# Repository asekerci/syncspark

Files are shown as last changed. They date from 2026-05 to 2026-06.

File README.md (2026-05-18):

# SynchroSpark Swarm: Mobile Robots for Exploring Swarming, Synchronization, and Formation Control Algorithms

<p align="center">
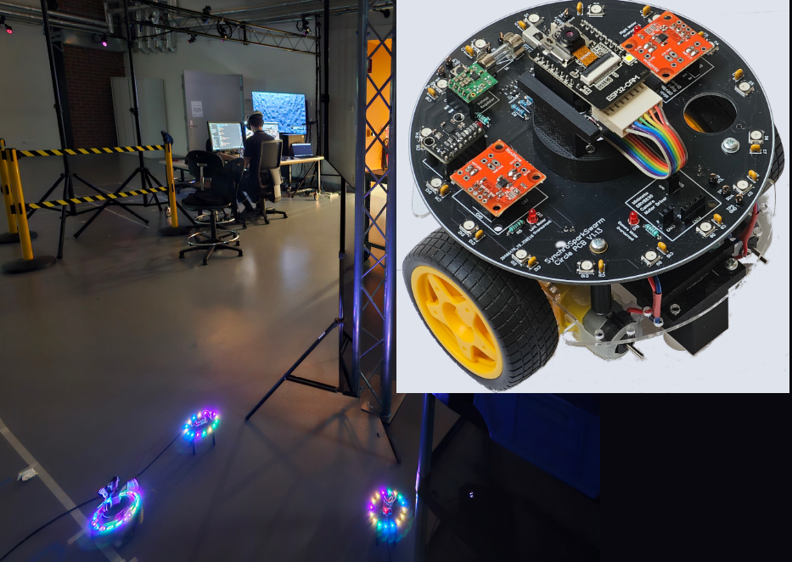
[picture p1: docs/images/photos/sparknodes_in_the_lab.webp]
Three SparkNode prototypes used in the SyncSpark project
  
</p>

## Table of Contents

- [Introduction](#introduction)
- [Project Objectives](#project-objectives)
  - [Formation Control Algorithms](#formation-control-algorithms)
  - [Research Collaboration](#research-collaboration)
- [Licensing](#licensing)
- [Project Structure and Terminology](#project-structure-and-terminology)
  - [About the Repository](#about-the-repository)
  - [AI Thinker ESP32-CAM Module](#ai-thinker-esp32-cam-module)
  - [Software Development Platform](#software-development-platform)
- [Testbed Configuration and Operation](#testbed-configuration-and-operation)
  - [Remote Control of SparkNodes with MQTT](#remote-control-of-sparknodes-with-mqtt)
  - [Over-the-Air (OTA) Method for Firmware Upgrades](#over-the-air-ota-method-for-firmware-upgrades)
- [Programs for Testing and Demonstrating Various Functionalities](#programs-for-testing-and-demonstrating-various-functionalities)
  - [OTA Enabled Programs](#ota-enabled-programs)
  - [Directly Flashable Programs](#directly-flashable-programs)
- [Appendix A: Additional Steps to Create an ESP-IDF Project From Scratch](#appendix-a-additional-steps-to-create-an-esp-idf-project-from-scratch)
- [Appendix B: ESP32-CAM Configuration](#appendix-b-esp32-cam-configuration)
- [Appendix C: Custom Partition Table](#appendix-c-custom-partition-table)

## Introduction

We[^1] are developing a network of low-cost mobile robots for exploring swarming, synchronization, and formation control algorithms, hence the name
**SynchroSpark Swarm**. The project's short name is **SyncSpark**, which is
also the name of our main GitHub repository.

Each robot, called a **SparkNode**, features a wheeled base with two motors and
an ESP32-CAM AI-Thinker module. At present, the module is mounted in a fixed
position, but we plan to place it on a motorized rotating platform in a future
revision. That change will let us control the camera angle for 360-degree
observation and better support the study of fully localized algorithms.

## Project Objectives

When we started designing the SparkNodes, our goal was to experiment with
cooperative robotics and explore the intersection of art and technology, with a
particular focus on collaborative robot art. To support that goal, we wanted a
mobile robot platform that was low-cost, compact, practical to build in
quantities of 30 to 40 units, well connected, and easy to track, at least at the
level of relative pose.

These constraints shaped the project from the beginning. Because cost is a
central concern, our robots do not rely on sophisticated sensors. Instead, we
build on several low-cost localization strategies drawn from our past research,
including:

- The use of RGB LED rings and cameras, as described in [Partitioning de Bruijn
  Graphs Into k-cycles for Robot Identification and
  Tracking](https://sekerci.info/~ahmet/papers/de_bruijn_cycles.pdf) (T.
  Grubman, Y. A. Sekercioglu, and D. Wood), and
- Trilateration methods, as explored in
  [Accurate Node Localisation in Ad Hoc Networks Using Directional Pulsed
  Infrared Light
  Communications](https://sekerci.info/~ahmet/pgrad-projects/joseph-thesis.pdf)
  (J. Violi, MEngSc. Thesis).

The concepts developed in these studies provide the technical basis for implementing formation control algorithms on the swarm and, ultimately, creating coordinated dynamic art displays.

<p align="center">
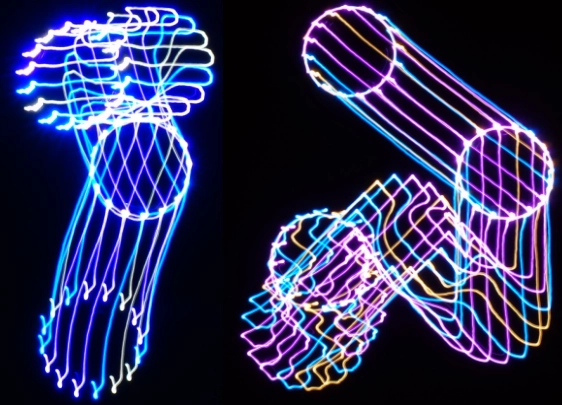
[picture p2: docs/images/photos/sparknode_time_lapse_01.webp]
Long-exposure image of two SparkNodes creating light trails during motion
  
</p>

<p align="center"><em>Long-exposure image of two SparkNodes moving randomly, illustrating the project's potential for collaborative robot art.</em></p>

### Formation Control Algorithms

Based on our past research in [formation control techniques](https://sekerci.info/~ahmet/networked_robotics/history.html), we believe that well-established decentralized algorithms are the right starting point for this platform. They allow us to study how simple local interaction rules can produce emergent collective behaviour. The [Boids algorithm](https://en.wikipedia.org/wiki/Boids) is a natural first example and will serve as our initial demonstration project.

Our second line of work is "Distributed Formation Control Using Computational Energy Minimization." This approach is inspired by our earlier work, [Virtual Localization for Mesh Network Routing](https://sekerci.info/~ahmet/mesh/virt_loc/) (N. Moore, Y. A. Sekercioglu, and G. K. Egan). In this approach, each robot moves toward a position that minimizes a local computational energy function, allowing formations to emerge without central coordination.

In our virtual localization study, static nodes iteratively estimated their positions by minimizing a local potential based on the virtual positions of their one-hop and two-hop neighbours, which were also computed iteratively. Although that idea was originally applied to sensor-network localization in support of geographic routing, the same principle can be adapted to mobile robots by translating virtual positions into real motion.

### Research Collaboration

The project has also grown into a research collaboration with the [Shortest Path Lab (SPL)](https://pathfinding.ai) at Monash University, led by A/Prof Daniel Harabor. This collaboration focuses on building a mobile robot network for testing multi-agent pathfinding algorithms in realistic physical scenarios.

SPL works on AI planning and heuristic search algorithms for single-agent and multi-agent pathfinding problems, including trip planning in transportation networks, motion planning and navigation for mobile robots, and automated warehouse logistics. SyncSpark provides a practical testbed for moving some of those ideas out of simulation and into embodied multi-robot experiments.

As part of this collaboration, we also extended the project into the mixed-reality world by creating [SparkVerse](./docs/system/sparkverse.md), a virtual environment for testing algorithms before physical implementation. Together, the physical SparkNode platform and SparkVerse allow us to study these ideas across both simulated and real-world settings.

## Licensing

This repository contains both software and hardware design materials, so its licensing is organized by content type.

- Software source code is licensed under the GNU General Public License v3. See [LICENSES/GPL-3.0.txt](./LICENSES/GPL-3.0.txt).
- Hardware design files under [docs/hardware](./docs/hardware) are licensed under the CERN Open Hardware Licence Version 2 - Strongly Reciprocal. See [docs/hardware/README.md](./docs/hardware/README.md) and [LICENSES/CERN-OHL-S-2.0.txt](./LICENSES/CERN-OHL-S-2.0.txt).

If a file or subdirectory carries a different license notice, that notice takes precedence for that material.

## Project Structure and Terminology

### About the Repository

This repository is organized as an umbrella project (or monorepo) that contains multiple ESP-IDF application projects and shared components:

- **Umbrella Project (Monorepo):** The top-level directory (`syncspark`) that
  contains several ESP-IDF application projects and common components.
- **Application Project (Subproject):** Each subdirectory under the umbrella
  (e.g., `sparknode_cam_wifi`, `sparknode_ota_updater`) that represents a standalone
  ESP-IDF project with its own `main` folder, `sdkconfig`, etc.
- **Component:** Shared code or libraries (e.g., in `components/`) that can be
  reused by multiple application projects.

Throughout this documentation, these terms are used to distinguish between the
overall repository, the individual ESP-IDF projects, and the reusable code
modules.

At a practical level, the top-level repository is centered around a small set of
directories:

- [components](./components/): shared ESP-IDF components reused across projects.
- [docs](./docs/): hardware, architecture, and supporting project documentation.
- [system](./system/): host-side utilities such as OTA packaging and log collection.
- [sparkcore](./sparkcore/): the primary OTA-enabled firmware for SparkNodes.
- [sparknode_ota_updater](./sparknode_ota_updater/README.md): the factory-partition OTA updater.
- [get_esp32_chip_info](./get_esp32_chip_info/README.md): the simplest direct-flash sanity check for a board/toolchain.

### AI Thinker ESP32-CAM Module

We use the AI Thinker ESP32-CAM module, which is built around the original dual-core
ESP32 chip (not the newer ESP32-S2, ESP32-S3, or ESP32-C3 variants). The module
provides WiFi and Bluetooth capabilities and has the following specifications:
a 240 MHz clock speed, 520 KB of RAM, 8 MB of PSRAM (SPIRAM)[^2], and 4 MB of flash memory.

### Software Development Platform

We use the [Espressif IoT Development
Framework (ESP-IDF)](https://github.com/espressif/esp-idf). [Visual Studio Code](https://code.visualstudio.com/), paired with the [ESP-IDF
extension](https://docs.espressif.com/projects/vscode-esp-idf-extension/en/latest/),
provides an effective development environment.

To test the toolchain, we use a small program called
[`get_esp32_chip_info`](get_esp32_chip_info/README.md), which reports information
about the chip and its capabilities. This program should be flashed directly to the
factory partition via a USB cable.

## Testbed Configuration and Operation

<p align="center">
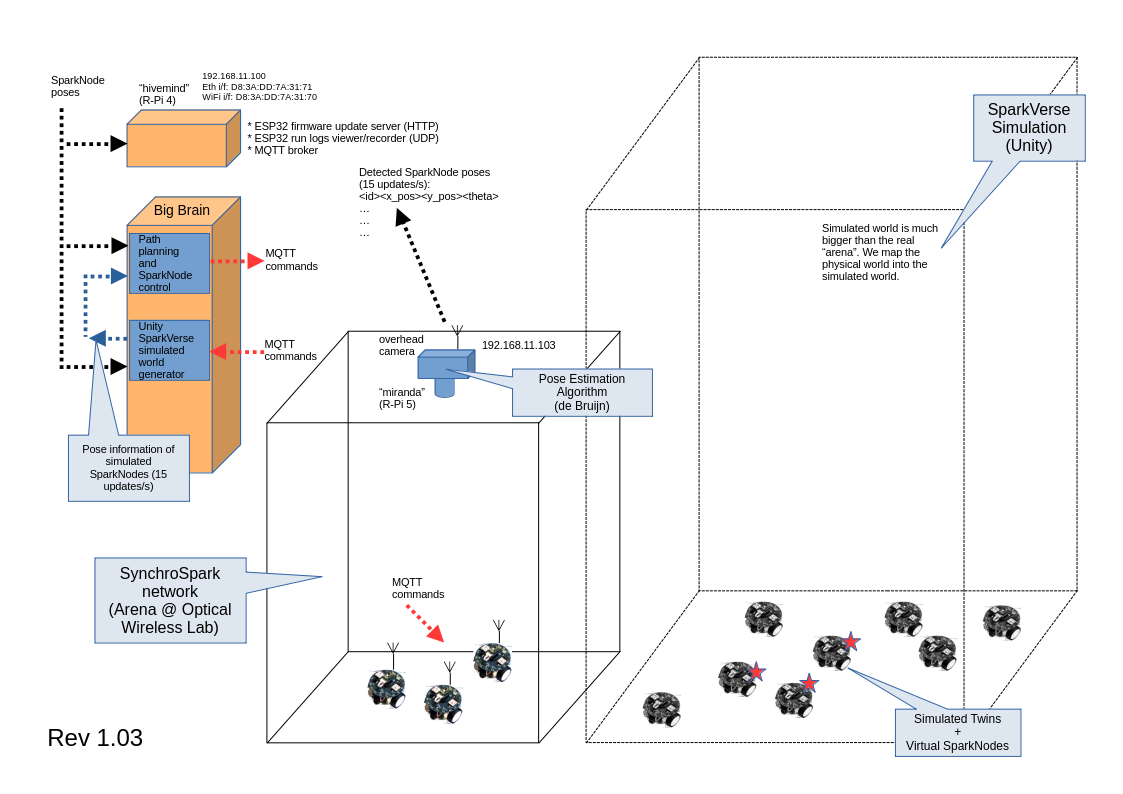
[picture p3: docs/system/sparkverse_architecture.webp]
Robotics Lab testbed
  
</p>

<p align="center"><em>The robot-network setup at the Monash Optical Wireless Systems Laboratory. The diagram also shows the Unity-based simulation environment. The Unity simulation environment has its own separate GitHub repository, which is currently under preparation.</em></p>

### Remote Control of SparkNodes with MQTT

We are progressively adding MQTT commands for the remote control of SparkNodes. See
[the information and list of commands](./docs/software/mqtt.md) for details.

### Over-the-Air (OTA) Method for Firmware Upgrades

We primarily use the over-the-air (OTA) method for firmware upgrades, as
described below. Our OTA firmware update method offers two main advantages:

1. It eliminates the need for USB cable connections, allowing us to quickly
   deploy firmware updates and bring a SparkNode online for testing.
2. Since we plan to have at least 30 SparkNodes in our SynchroSpark Swarm, the OTA method enables us to efficiently update firmware on all of them.

However, the OTA method requires a WiFi LAN, and directly flashing programs is
sometimes more useful for testing basic functionality. For that reason, we group our ESP-IDF projects into two categories:

- [OTA enabled programs](#ota-enabled-programs), and
- [Directly flashable programs](#directly-flashable-programs)

We provide the example application `sparknode_sample_ota_app`, which
demonstrates the basic operation of OTA-enabled firmware. When
`sparknode_ota_updater` is installed in the factory partition of the ESP32-CAM, all other applications should be built from `sparknode_sample_ota_app` as a starting point. These applications are designed to be delivered via OTA updates and should not be flashed directly to the chip over USB.

See [sparknode_ota_updater/README.md](sparknode_ota_updater/README.md) for
detailed information about our OTA firmware update scheme.

[Follow these steps](./docs/software/ota.md) to create OTA-capable firmware. If you need to create a new ESP-IDF project from scratch, see [Appendix A: Additional Steps to Create an ESP-IDF Project From
Scratch](#appendix-a-additional-steps-to-create-an-esp-idf-project-from-scratch).

## Programs for Testing and Demonstrating Various Functionalities

### OTA Enabled Programs

- **[`sparkcore`](sparkcore/)**: The main firmware we run on
  the SparkNodes.
- **[`sparknode_sample_ota_app`](sparknode_sample_ota_app/README.md)**: Used for
  testing and demonstrating the OTA firmware update method. It can serve as
  a starting point for new SyncSpark firmware.
- **[`sparknode_ledring`](sparknode_ledring/README.md)**: For testing the RGB LED
  ring control routines.
- **[`sparknode_mqtt`](sparknode_mqtt/README.md)**: For experimenting
  with MQTT. The `scripts` directory contains examples of
  SparkNode remote control.
- **[`sparknode_drive_test`](sparknode_drive_test/README.md)**: For testing the
  motor drivers.
- **[`sparknode_cam_wifi`](sparknode_cam_wifi/README.md)**: Demonstrates basic
  networking by periodically sending captured image frames to a remote host
  via UDP datagrams over WiFi.
- **[`sparknode_icm20948`](sparknode_icm20948/README.md)**: Performs sensor
  calibration and data acquisition using the ICM20948 9-axis IMU and BMP388
  barometric pressure sensors, and applies the Madgwick sensor fusion
  algorithm for accurate orientation estimation.
- **[`sparknode_i2c_test`](sparknode_i2c_test/README.md)**: For testing I2C
  communication with the motor controllers, BMP388 sensor, and GY-912 IMU board,
  and for verifying RGB LED ring operation.
- **[`sparknode_hall_sensors`](sparknode_hall_sensors/README.md)**: Tests the
  hall-effect sensor routines using interrupts.

### Directly Flashable Programs

- **[`get_esp32_chip_info`](get_esp32_chip_info/README.md)**: Reports on the
  configuration of the chip and performs quick checks.
- **[`sparknode_ota_updater`](sparknode_ota_updater/README.md)**: Flashed
  directly into the factory partition once to enable OTA firmware updates. It must
  remain resident in the factory partition for proper operation of OTA firmware
  updates.
- **[`glow_ledring`](glow_ledring/README.md)**: Illuminates the RGB LED ring
  with the assigned de Bruijn sequence (we allocate unique IDs to each
  SparkNode by using their base MAC addresses).
- **[`opti_pose`](opti_pose/README.md)**: Periodically captures images. We plan
  to use it to develop pose estimation algorithms that will run directly on the
  ESP32-CAM.

## Appendix A: Additional Steps to Create an ESP-IDF Project From Scratch

1. **Navigate to the main SyncSpark project directory:**

   ```bash
   cd $HOME/projects/syncspark/
   ```

2. **Create a new project:**

   ```bash
   idf.py create-project my_esp_project
   ```

   Replace `my_esp_project` with your desired project name. This command
   creates a directory named `my_esp_project` under the current directory and
   populates it with starter files and subdirectories.

3. **Set target:**

   ```bash
   cd my_esp_project && idf.py set-target esp32
   ```

   The ESP32-CAM uses the original ESP32 chip (ESP32-WROOM-32).

After creating your new project, follow the remaining steps in the
[OTA workflow documentation](./docs/software/ota.md).

## Appendix B: ESP32-CAM Configuration

Before generating a binary to run on a SparkNode, several ESP32 chip
properties must be configured, and a custom partition table must be
established. To accomplish this, we created an `sdkconfig.defaults` file.
Using this file, the toolchain configures the following properties correctly:

- **Serial flasher config**: Increases the flash size to 4 MB.
- **Serial flasher config → Flash SPI speed**: Increases to 80 MHz.
- **Component config → ESP System Settings**: Increases the clock speed to 240
  MHz.
- **Component config → ESP PSRAM**: Enables support for PSRAM.
- **Component config → ESP PSRAM → Support for external, SPI connected RAM →
  SPI_RAM config → set RAM speed**: Sets to 80 MHz.
- **Partition Table → custom partition table CSV**: Selects this option and
  sets 0x8000 as the "Offset of partition table".

The standard `sdkconfig.defaults` file is located in the top-level directory of
the SynchroSpark project. The top directory of each individual ESP-IDF project
contains a symbolic link that points to it.

See [sdkconfig and configuration
management](docs/software/about_sdkconfig.md) for further details.

## Appendix C: Custom Partition Table

All OTA-enabled programs use the standard partition table shown below. The main
directory of each OTA-enabled program contains a symbolic link to this standard
partition table.

```bash
    # SynchroSpark Project partition table
    # --> ESP-IDF requires partitions to be aligned to a 4 KB boundary
    # (multiples of 0x1000). In addition to this:
    # --> Partitions of type "app" have to be placed at offsets
    # aligned to 64 KB boundary (multiples of 0x10000).
    #
    # Name,   Type, SubType, Offset,  Size, Flags
    nvs,      data, nvs,     0x9000,  0x6000,
    phy_init, data, phy,     0xf000,  0x1000,
    factory,  app,  factory, 0x10000, 0xF8000,
    ota_data, data, ota,     0x108000,0x2000,
    ota_0,    app,  ota_0,   0x110000,0x2F0000
```

Note that the directly flashable programs use the built-in default partition
table.

## Footnotes

[^1]: Ahmet Sekercioglu and Ismet Atalar, creators of the SyncSpark project.

[^2]: Unfortunately, the current version of ESP-IDF allows us to use only half of the available PSRAM capacity.

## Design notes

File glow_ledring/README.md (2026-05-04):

# RGB LED Ring Illumination
## Overview

This program illuminates the RGB LED ring of a sparknode with the 
assigned deBruijn sequence. 

## ESP32-CAM and ESP-IDF Configuration

Configuration details are in 
the main [README.md](../README.md) file of the **SyncSpark** project.

## Required Components

Run the following commands  in the top directory of the project:

1. **espressif/led_strip**, to add:
 `idf.py add-dependency "espressif/led_strip^3.0.0"`

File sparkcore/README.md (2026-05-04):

# Main Firmware of SparkNodes 

## Overview

This is the firmware we run on the SparkNodes. We install 
it through the OTA method. 

## ESP32-CAM and ESP-IDF Configuration

Configuration details (including the partition table) are in 
the main [README.md](../README.md) file of the **SyncSpark** project.

## Required Components

1. espressif/led_strip:  
 `idf.py add-dependency "espressif/led_strip^3.0.0"`

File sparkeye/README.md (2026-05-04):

sparkeye runs on a camera attached Raspberry Pi 5 to track SparkNodes. 
It has its own separate github repository.

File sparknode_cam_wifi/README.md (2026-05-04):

# _sparknode_cam_wifi_

## ESP32-CAM
Clock speed: 240 MHz, 520 KB RAM, 8 MB PSRAM (SPIRAM), 4 MB flash memory

## About the Program

This program takes a picture every 20 seconds and sends it to a
destination over UDP.

My starting point was the example program provided in the Espressif
esp32-camera component. I removed the parts that are not related
esp32-cam. 

## ESP32-CAM and ESP-IDF Configuration

Configuration details  are in 
the main [README.md](../README.md) file of the **SyncSpark** project.

### Required Components

1. Run this command in the top directory of the project to add the `espressif/esp32-camera component`: 
   `idf.py add-dependency "espressif/esp32-camera^2.0.15"`
2. If you want to have more control over the camera and
   how it will be initialized, you can have your own `Kconfig` file. Copy the content from
   `https://github.com/espressif/esp32-camera/blob/master/Kconfig` into a local `Kconfig`.
   This file should reside in the `main` directory. Currently we use the default one residing in the esp32-camera component.

## Usage and Specific Configurations

### Wi-Fi Connection

Copy the file `wifi_credentials.h.template` to `wifi_credentials.h` (in the `main` directory) and then edit it to set the WiFi SSID and password to connect to your own Wi-Fi network (`wifi_credentials.h` will **not** be uploaded to the github repository). 

### Network Configuration 

We send two separate UDP datagrams to a remote host: One for images, 
and one for the copies of the log messages. 
See `network_config.h.template` for further details. Copy `network_config.h.template` to a file `network_config.h` and edit the remote host's details. 

### Receiving Images

In my case, the destination is my homelab Linux server `rama.local` (`192.168.1.201`), and 
the destination UDP port is `10000`.

On `rama`, I run the python program `rcv_frames_udp.py` to save 
the received image frames. The program is in the top project directory. It saves the received frames in the `frames` directory. In order to run it on `rama`, I first link my RPi5 home directory to `rama`'s `~/systems/sinope` directory by using the command 
`sshfs sinope.local: ~/systems/sinope`. Then, I run the command `rcv_frames_udp.py` on `rama` to listen to the messages sent by the robot (to-do: we need to create a more sophisticated program for receiving image frames from multiple robots simultaneously).

### Receiving Copies of Log messages

The robot sends the copies of log messages to UDP port 10001 of `rama`. Run the command `nc -u -l 10001` on a terminal to display them.  

## Espressif's Notes

- A recommended way is to follow the instructions on this [docs page](https://docs.espressif.com/projects/esp-idf/en/latest/api-guides/build-system.html#start-a-new-project).

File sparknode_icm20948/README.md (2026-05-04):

# ICM20948 IMU Chip Calibration and Experiments
## Overview

- Supports the ICM20948 9-axis IMU sensor and BMP388 barometric pressure sensor via I2C.
- Performs sensor calibration and data acquisition.
- Implements Madgwick sensor fusion algorithm for orientation estimation.

## ESP32-CAM and ESP-IDF Configuration

Configuration details are in 
the main [README.md](../README.md) file of the **SyncSpark** project.

## Required Components

Run the following command  in the top directory of the project:

1. **espressif/led_strip**:
 `idf.py add-dependency "espressif/led_strip^3.0.0"`

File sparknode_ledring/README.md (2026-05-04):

# SparkNode RGB LED Ring deBruijn Patterns Demo
## Overview

This program lights up the RGB LED ring of a sparknode with the
assigned deBruijn sequence. 

It is MQTT enabled. 

## ESP32-CAM and ESP-IDF Configuration

Configuration details (including the partition table) are in 
the main [README.md](../README.md) file of the **SyncSpark** project.

## Required Components

1. espressif/led_strip:  
 `idf.py add-dependency "espressif/led_strip^3.0.0"`

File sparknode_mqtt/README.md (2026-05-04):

# MQTT Demo

## Overview

This ESP-IDF project is for testing the MQTT scheme, which enables remote 
control of SparkNodes via MQTT commands. 

The remote control commands include driving forward/reverse, turn left/right, stop
immediately, and reboot on command. We keep adding the new ones.    

The details are [here](../docs/software/mqtt.md).

## ESP32-CAM and ESP-IDF Configuration

Configuration details (including the partition tabl) are in the main
[README.md](../README.md) file of the **SyncSpark** project.

## Required Components

1.  espressif/led_strip:\
    `idf.py add-dependency "espressif/led_strip^3.0.0"`

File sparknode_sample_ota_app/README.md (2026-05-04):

# SparkNode Sample Over-The-Air (OTA) Application
## Overview

When the chip is programmed for the very first time, 
we flash `sparknode_ota_updater` in the `factory` partition by using a
USB cable.

 Then, whenever the chip is rebooted, or power-cycled, it 
 downloads a binary file and its corresponding MD5 checksum from the server specified in `network_config.h`. If the download is successful, the binary is written to the `ota_0` partition, the boot partition is set to `ota_0`, and the chip is restarted.

On subsequent boots, if the downloaded binary is properly configured 
the application changes the boot partition to `factory` to check the 
availability of updated firmware by running `sparknode_ota_updater` 
at every restart. 

This is a sample application that can be used as a starter for all
firmware sources for the SynchroSpark Project. 

## ESP32-CAM and ESP-IDF Configuration

Configuration details (including the partition table) are in 
the main [README.md](../README.md) file of the **SyncSpark** project.

## Software Configuration Before the First Compilation 

Configuration details (including the partition table) are in 
the main [README.md](../README.md) file of the **SyncSpark** project.

## Required ESP-IDF Components

- led_strip, run this command:
```bash
   idf.py add-dependency "espressif/led_strip^3.0.0"
```

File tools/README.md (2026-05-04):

# Python Tools Summary

## mqtt_orientation_viewer.py
Live 3D viewer for yaw/pitch/roll over MQTT. Renders a simple 3‑wheel robot model.

Usage:
```bash
python mqtt_orientation_viewer.py --broker 192.168.1.19 --node sparknode03
```

Options:
- `--topic <topic>`: override topic (default: `arena/<node>/orientation`)
- `--poll-ms <int>`: UI update interval (ms)
- `--yaw-offset <deg>`: alignment offset (default -90)
- `--invert-yaw`, `--invert-pitch`, `--invert-roll`

Notes:
- Requires `numpy`, `matplotlib`, `paho-mqtt`.
- Needs an interactive backend (PyQt5 or Tk). If none found, it fails with a message.

## mag_calibrate_3d_all_in_one.py
All‑in‑one 3D magnetometer calibration pipeline: capture samples → fit ellipsoid → apply calibration.

Usage:
```bash
python mag_calibrate_3d_all_in_one.py --broker 192.168.1.19 --node sparknode03 --samples 500 --delay-ms 50
```

Options:
- `--mode all|capture` (default: `all`)
- `--timeout-s <sec>`
- `--output <csv>`
- `--target-radius <uT>` (optional fixed scaling)

Notes:
- Uses `mosquitto_sub` and `mosquitto_pub`.
- Default output: `mag_capture_<node>.csv`.

## mag_capture_to_csv.py
Captures raw magnetometer samples into a CSV file.

Usage:
```bash
python mag_capture_to_csv.py --broker 192.168.1.19 --node sparknode03 --samples 500 --delay-ms 50 --trigger
```

Options:
- `--trigger`: sends `calibrate mag capture <samples> <delay_ms>` before listening.
- `--output <csv>`
- `--timeout-s <sec>`

## plot_heading_vs_euler.py
Plots heading vs yaw (top) and pitch/roll (bottom) from a log `.txt` or a CSV.
Also writes optional CSV output and annotates filename, start/stop times, and mode.

Usage (TXT input):
```bash
python plot_heading_vs_euler.py log_YYYYMMDD_HHMMSS.txt --csv-out heading_vs_yaw_YYYYMMDD.csv
```

Usage (CSV input):
```bash
python plot_heading_vs_euler.py heading_vs_yaw_YYYYMMDD.csv
```

Options:
- `--no-unwrap`: keep 0–360 wrap instead of unwrapped angles

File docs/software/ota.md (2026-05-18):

#### OTA: One-Time Setup

Before generating any binaries, complete the following steps:

1. **Configure template files:** Locate
   [`wifi_credentials.h.template`](./components/syncspark_config/include/wifi_credentials.h.template)
   and
   [`network_config.h.template`](./components/syncspark_config/include/network_config.h.template)
   in the
   [`components/syncspark_config/include`](./components/syncspark_config/include/)
   directory, then follow these steps:
   1. **WiFi Connection**: Copy the contents of `wifi_credentials.h.template`
      to a new file named `wifi_credentials.h`[^3] and update the WiFi
      connection information as described in the file comments.
   2. **IP Address Configuration**: Copy the contents of
      `network_config.h.template` to a new file named `network_config.h`[^4]
      and update the IP addresses as described in the comments.
2. **Flash the OTA updater:** Flash `sparknode_ota_updater` directly over USB
   cable (**this will be placed in the _factory_ partition by default**), then
   disconnect the USB cable. Here are the **detailed flashing steps**
   (assuming the ESP-IDF toolchain is installed in `$HOME/esp`, version v5.5,
   and the SyncSpark repository is cloned to `$HOME/projects/syncspark`):
   1. Set up the environment: `source $HOME/esp/v5.5/esp-idf/export.sh`
   2. Navigate to the updater directory:
      `cd $HOME/projects/syncspark/sparknode_ota_updater`
   3. Configure the project: `idf.py reconfigure` (this command generates a
      `sdkconfig` from the `sdkconfig.defaults`).
   4. Build the binary: `idf.py build`
   5. Prepare the ESP32-CAM for flashing: Connect the ESP32-CAM to your
      computer via a USB cable. Press and hold the IO0 button, then press the
      ESP32-CAM reset button. Release the reset button first, then release the
      IO0 button. The chip is now ready for flashing.
   6. Flash and monitor: `idf.py flash monitor` (this command flashes the
      firmware to the factory partition).

The board is now ready for OTA updates. Disconnect the USB cable.

#### OTA: Typical Workflow

To generate a binary for an existing [SynchroSpark
program](#programs-for-testing-and-demonstrating-various-functionalities)[^5] in
the repository (for example, to run `sparknode_sample_ota_app` on a SparkNode
after cloning the SynchroSpark project sources to `$HOME/projects/syncspark`),
follow these steps:

1. **Activate the HTTP Server and Log Listener:**
   - Run the HTTP server on the target host (see the command in `network_config.h`)
   - Run [`log_listener.py`](./system/utilities/log_listener.py) on the
     listener host

2. **Set up the environment:**

   ```bash
   source $HOME/esp/v5.5/esp-idf/export.sh
   ```

   (Your ESP-IDF version may differ; please check your installation
   directory.)

3. **Navigate to the program's main directory:**

   ```bash
   cd $HOME/projects/syncspark/sparknode_sample_ota_app
   ```

4. **Add required dependencies:** Some projects require additional ESP-IDF
   standard components. For example, `sparknode_led_ring` needs the RGB LED
   strip component. To add it, run:

   ```bash
   idf.py add-dependency "espressif/led_strip^3.0.0"
   ```

   Please refer to each project's `README.md` for required system
   components.

5. **Configure the project:** Run:

   ```bash
   idf.py reconfigure
   ```

   to configure system parameters and set a custom partition table. For
   details, see [Appendix B: ESP32-CAM
   Configuration](#appendix-b-esp32-cam-configuration) and [Appendix C: Custom
   Partition Table](#appendix-c-custom-partition-table).

6. **Build the project:** Run:

   ```bash
   idf.py build
   ```

   in the top directory of the program (e.g.,
   `$HOME/projects/syncspark/sparknode_sample_ota_app`).

7. **Prepare the OTA binary:** Run:

   ```bash
   ../system/utilities/prep_ota_bin.sh <SparkNodeID>
   ```

   in the top directory of the program. Here, `<SparkNodeID>` is a number
   between 1 and 99 (we assign a `SparkNodeID` to each robot).

8. **Verify binary preparation:** Confirm that the `../system/ota` directory
   now contains the updated `*.bin`, `*.md5`, and the associated timestamp
   file.

9. **Reset the SparkNode:** Press the reset button on the SparkNode's
   ESP32-CAM.

To create a new ESP-IDF project from scratch, see [Appendix A: Additional Steps
to Create an ESP-IDF Project From
Scratch](#appendix-a-additional-steps-to-create-an-esp-idf-project-from-scratch).

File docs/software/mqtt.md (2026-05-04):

# SparkNode MQTT Control Commands

## Table of Contents

- [Communication](#communication)
- [Configuration Commands](#configuration-commands)
- [Movement Commands](#movement-commands)
- [IMU Sensor System](#imu-sensor-system)
  - [IMU Data Topics](#imu-data-topics)
    - [Orientation Data](#orientation-data)
    - [Orientation Data by Sensor Mode](#orientation-data-by-sensor-mode)
  - [IMU Calibration Commands](#imu-calibration-commands)
  - [IMU Control Commands](#imu-control-commands)
- [System Commands](#system-commands)
- [Command Behavior](#command-behavior)
- [Example Usage](#example-usage)
  - [Movement Examples](#movement-examples)
  - [Configuration Examples](#configuration-examples)
  - [Sensor Control Examples](#sensor-control-examples)
  - [IMU Calibration Examples](#imu-calibration-examples)
  - [Navigation Examples](#navigation-examples)
  - [Scripted Command Sequences](#scripted-command-sequences)
- [Implementation Notes](#implementation-notes)
- [Per-SparkNode Configuration](#per-sparknode-configuration)
- [Appendix A: MQTT System](#appendix-a-mqtt-system)

## Communication

-   **Topic to send commands to an individual SparkNode**: `arena/sparknodeXX/cmd` (where `sparknodeXX` is the ID 
   of the SparkNode you want to control). Example:
```bash
      mosquitto_pub -h <broker_ip> -t "arena/sparknode01/cmd" -m "drive forward 32 5000"
```
-   **Topic to send commands to all SparkNodes (broadcast)**: `arena/all/cmd`
-   **Status responses appear on**: `arena/sparknodeXX/status`. The command to listen to these messages is:
```bash
      mosquitto_sub -h $broker_address -t 'arena/+/status'
```

## Configuration Commands

-   `config show` - Display the current SparkNode configuration
-   `config set drive_kick <speed> <duration>` - Set drive kick parameters
    (speed: 16-63, duration: 50-500ms)
-   `config set turn_kick <speed> <duration>` - Set turn kick parameters (speed:
    10-63, duration: 25-500ms)
-   `config set wheel_calibration <left> <right>` - Set wheel speed calibration
    factors (0.5-2.0)
-   `config set default_speed <speed>` - Set the default movement speed (0-63)

## Movement Commands

-   `drive forward <speed> <duration>` - Drive forward at the specified speed (0-63)
    for the given duration (ms)
-   `drive reverse <speed> <duration>` - Drive backward at the specified speed
    (0-63) for the given duration (ms)
-   `turn left <speed> <duration>` - Turn left at the specified speed (0-63) for
    the given duration (ms)
-   `turn right <speed> <duration>` - Turn right at the specified speed (0-63) for
    the given duration (ms)
-   `rotate to <angle> [speed] [step_ms] [delay_ms] [tolerance]` - Rotate to a specific magnetometer heading (0-360 degrees)
    - `angle` - Target heading in degrees (0-360, required)
    - `speed` - Fixed rotation speed (0-63, default: 15)
    - `step_ms` - Duration of each rotation step in milliseconds (minimum: 5, default: 10)
    - `delay_ms` - Delay between heading checks in milliseconds (minimum: 100, default: 300)
    - `tolerance` - Acceptable heading error in degrees (minimum: 5.0, default: 5.0)
    - Uses fixed speed for all rotation steps
-   `turn to <angle> [speed]` - Continuously turn to target heading with proportional speed control
    - `angle` - Target heading in degrees (0-360, required)
    - `speed` - Maximum rotation speed (0-63, default: 20)
    - Uses vector averaging of 3 magnetometer samples per iteration for stable heading
    - Proportional speed ramping based on heading error (minimum speed: 12)
    - Stops when within 5° tolerance
-   `stop` - Immediately halt both motors (brake then coast)

## IMU Sensor System 

### IMU Data Topics

SparkNodes publish sensor data to specific topics when enabled:

#### Orientation Data

-   **Topic**: `arena/sparknodeXX/orientation`
-   **Publishing**: Automatically published when sensor streaming is enabled via `sensor_stream start`
-   **Format**: JSON payload with Euler angles (in degrees) (example payload: `{"yaw":85.32,"pitch":2.15,"roll":-1.03}`)
-   **Update rate**: Configurable via `sensor_stream start [period_ms]` (minimum: 20ms)
-   **Data source**: Computed using Madgwick AHRS algorithm for sensor fusion
-   **Subscribe to all nodes**: 
```bash
      mosquitto_sub -h <broker_ip> -t 'arena/+/orientation'
```

#### Orientation Data by Sensor Mode

The orientation data varies based on the active sensor mode:

-   **`mag_accel_gyro`** (default) - Full 9-DOF sensor fusion
    - Provides: yaw (0-360°), pitch, and roll from magnetometer + accelerometer + gyroscope
    - Uses Madgwick filter for accurate orientation in 3D space
    - Best for complete orientation tracking

-   **`accel_gyro`** - 6-DOF sensor fusion (no magnetometer)
    - Provides: yaw (with +90° alignment offset), pitch, and roll from accelerometer + gyroscope
    - Suitable when magnetic interference is present
    - Note: Yaw may drift over time without magnetometer correction

-   **`mag`** - Magnetometer-only mode
    - Provides: yaw from magnetometer heading only
    - pitch and roll are set to 0.0
    - Useful for heading-only applications

-   **`mag_accel`** - Magnetometer + accelerometer fusion
    - Provides: yaw from magnetometer, pitch and roll from accelerometer
    - No gyroscope drift correction

### IMU Calibration Commands

-   `calibrate gyro` - Recalibrate gyroscope bias and save to NVS (non-volatile storage)
-   `calibrate mag <mode>` - Recalibrate magnetometer and save calibration data to NVS
    - `hard` - 2D calibration with flat rotation (robot automatically rotates)
    - `soft` - 3D calibration with figure-8 movement (manual movement required)
    - `capture [samples] [delay_ms]` - Capture raw magnetometer data for external calibration
        - samples: 100-1200 (default: 500)
        - delay_ms: 10-300ms between samples (default: 50ms)
        - Publishes each sample to MQTT for logging and external processing
        - Use for high-precision 3D calibration with external fitting tools
    - `apply <bias_x> <bias_y> <bias_z> <m00> <m01> <m02> <m10> <m11> <m12> <m20> <m21> <m22> [version]` - Apply externally computed calibration
        - Takes 3 hard-iron bias values and 9 soft-iron matrix values
        - Optional version parameter (1 or 3, default: 3)
        - Validates all values are finite before saving to NVS
-   `show calibrations` - Display current magnetometer and gyroscope calibration data
    (includes hard-iron bias, soft-iron matrix diagonal, and version info)

### IMU Control Commands

-   `sensor_loop <mode> [iterations] [delay_ms]` - Control the sensor data collection loop
    - `start [delay_ms]` - Run the sensor loop continuously
    - `stop` - Stop sensor data collection
    - `counted <iterations> [delay_ms]` - Run the sensor loop for a specified number of iterations
    - **Note**: The time interval between sensor readings is controlled by the `g_sensor_loop_delay_ms` global variable (default: 50ms)
-   `sensor_stream <start|stop|mode> [options]` - Control periodic sensor data streaming
    - `start [period_ms]` - Start streaming sensor data to `arena/sparknodeXX/orientation` topic (minimum period: 20ms)
    - `stop` - Stop sensor data streaming
    - `mode <mag_accel_gyro|accel_gyro|mag|mag_accel>` - Set which sensors to use for orientation computation
        - `mag_accel_gyro` - Full 9-DOF fusion (magnetometer + accelerometer + gyroscope) - default, best accuracy
        - `accel_gyro` - 6-DOF fusion (accelerometer + gyroscope only) - no mag, may drift
        - `mag` - Magnetometer-only heading (yaw only, pitch/roll = 0)
        - `mag_accel` - Magnetometer + accelerometer (no gyroscope)
-   `show heading [count] [delay_ms]` - Get the current magnetometer heading without moving the robot
    - `count` - Number of samples to average (default: 1)
    - `delay_ms` - Delay between samples in milliseconds (minimum: 10, default: 50)
    - Returns averaged heading with circular standard deviation and magnetic field magnitude statistics

## System Commands

-   `reboot` - Restart the SparkNode

## Command Behavior

**Drive/Turn Motion**:

-   Uses ramped acceleration/deceleration for smooth movement
-   Speed parameter: 0-63 (maps to PWM duty cycle: 0-100%)
-   Default speed: 32 (≈51% PWM duty cycle)
-   Runs in separate FreeRTOS tasks to keep MQTT responsive
-   Automatically stops and brakes at the end of the duration
-   **Kick-start mechanism**: Automatically applies higher initial torque to
    overcome static friction
-   **Sequencing**: Wait for command completion before sending next movement command

**Magnetometer-Based Navigation**:

-   **Show Heading**: Returns current magnetometer heading with optional multi-sample averaging and statistical analysis (circular standard deviation and magnetic field magnitude)
-   **Turn To (Proportional Control)**: Uses vector averaging of 3 magnetometer samples per iteration for stable heading. Speed is proportional to heading error with minimum speed of 12. Stops when within 5° tolerance
-   **Rotate To (Fixed Speed Control)**: Uses fixed rotation steps at constant speed. Default tolerance is 5° with a 100-iteration timeout. Default speed is 15, step duration is 10ms, and delay between checks is 300ms
-   **Closed-loop heading control**: Both turn commands use a calibrated magnetometer for accurate directional control
-   **Real-time feedback**: Publishes the current heading and progress during rotation
-   **Automatic sensor activation**: Temporarily enables the sensor loop during rotation for heading updates

**Stop Command**:

-   Immediate effect - applies brake mode briefly, then coast
-   Useful for emergency stops or interrupting ongoing motion

**Configuration System**:

-   **Per-SparkNode customization**: Each robot can have individual motor
    parameters
-   **Runtime configuration**: Settings are temporary and reset to defaults on
    reboot (no NVS storage)
-   **Motor calibration**: Compensates for manufacturing differences between
    left and right motors
-   **Kick parameters**: Customizes startup torque for different motor break-in
    states
-   **Real-time updates**: Configuration changes take effect immediately

**Sensor Control**:

-   **Sensor loop modes**: Controls when and how often IMU sensor data is collected and processed
-   **Real-time control**: Starts/stops sensor fusion processing on demand
-   **Counted mode**: Runs the sensor loop for a specific number of iterations for testing
-   **Sensor streaming**: Automatically publishes orientation data to `arena/sparknodeXX/orientation` topic
-   **Stream modes**: Flexible selection of which sensors to use for orientation computation:
    - **mag_accel_gyro**: Full 9-DOF Madgwick sensor fusion (most accurate)
    - **accel_gyro**: 6-DOF fusion without magnetometer (useful in magnetically noisy environments)
    - **mag**: Magnetometer-only heading (simple compass functionality)
    - **mag_accel**: Mag + accel fusion (no gyroscope)
-   **Data format**: JSON Euler angles in degrees: `{"yaw":xx.xx,"pitch":xx.xx,"roll":xx.xx}`
-   **Update rate**: Configurable from 20ms (50Hz) upward via period_ms parameter
-   **Sensor fusion algorithm**: Uses Madgwick AHRS filter for quaternion-based orientation estimation

**IMU Calibration**:

-   **Gyroscope calibration**: The robot must be stationary during the calibration process
-   **Magnetometer calibration**: Multiple modes available:
    - **Hard-iron (2D)**: Robot automatically rotates flat for calibration of hard-iron distortions
    - **Soft-iron (3D)**: Requires manual figure-8 movement for full 3D soft-iron distortion calibration
    - **Capture mode**: Collects raw magnetometer samples and publishes them via MQTT for external processing
    - **Apply mode**: Accepts externally computed calibration parameters (hard-iron bias and soft-iron matrix)
-   **External calibration workflow**: Capture raw data → process on host with advanced algorithms → apply results
-   **Persistent storage**: Calibration data is automatically saved to NVS and restored on reboot
-   **Status feedback**: Publishes success/failure status with calibration values
-   **Calibration inspection**: Use `show calibrations` to view current active calibration parameters

**Status Updates**:

-   Each accepted command publishes a confirmation with speed and duration details
-   Configuration changes publish acknowledgment messages
-   IMU calibration commands provide detailed feedback on calibration results
-   Unknown commands receive comprehensive help text

## Example Usage

Using `mosquitto_pub` or any MQTT client:

### **Movement Examples**

```bash
# Drive forward at speed 32 for 5000 milliseconds (5 seconds)
mosquitto_pub -h <broker_ip> -t "arena/sparknode01/cmd" -m "drive forward 32 5000"

# Turn right at speed 25 for 1500 milliseconds 
mosquitto_pub -h <broker_ip> -t "arena/sparknode01/cmd" -m "turn right 25 1500"

# Slow reverse movement at speed 15 for 2000ms
mosquitto_pub -h <broker_ip> -t "arena/sparknode01/cmd" -m "drive reverse 15 2000"

# Fast turn at speed 45 for 800ms
mosquitto_pub -h <broker_ip> -t "arena/sparknode01/cmd" -m "turn left 45 800"

# Rotate to 90 degrees (east) using default parameters
mosquitto_pub -h <broker_ip> -t "arena/sparknode01/cmd" -m "rotate to 90"

# Rotate to 180 degrees (south) with custom speed and precision
mosquitto_pub -h <broker_ip> -t "arena/sparknode01/cmd" -m "rotate to 180 25 30 200 3.0"

# Emergency stop
mosquitto_pub -h <broker_ip> -t "arena/sparknode01/cmd" -m "stop"

# Show current heading without moving
mosquitto_pub -h <broker_ip> -t "arena/sparknode01/cmd" -m "show heading"

# Turn to 90 degrees using proportional control
mosquitto_pub -h <broker_ip> -t "arena/sparknode01/cmd" -m "turn to 90"

# Turn to 180 degrees with custom max speed
mosquitto_pub -h <broker_ip> -t "arena/sparknode01/cmd" -m "turn to 180 30"

# Broadcast command to all sparknodes
mosquitto_pub -h <broker_ip> -t "arena/all/cmd" -m "stop"
```

### **Configuration Examples**

```bash
# Show current configuration
mosquitto_pub -h <broker_ip> -t "arena/sparknode01/cmd" -m "config show"

# Show current IMU calibration data
mosquitto_pub -h <broker_ip> -t "arena/sparknode01/cmd" -m "show calibrations"

# Set gentler drive kick for well-broken-in motors
mosquitto_pub -h <broker_ip> -t "arena/sparknode01/cmd" -m "config set drive_kick 25 100"

# Set stronger turn kick for stubborn motors  
mosquitto_pub -h <broker_ip> -t "arena/sparknode07/cmd" -m "config set turn_kick 40 250"

# Compensate for motor differences (left motor 5% weaker)
mosquitto_pub -h <broker_ip> -t "arena/sparknode03/cmd" -m "config set wheel_calibration 1.05 1.0"

# Set default movement speed
mosquitto_pub -h <broker_ip> -t "arena/sparknode01/cmd" -m "config set default_speed 28"
```

### **Sensor Control Examples**

```bash
# Start continuous sensor data collection
mosquitto_pub -h <broker_ip> -t "arena/sparknode01/cmd" -m "sensor_loop start"

# Start continuous sensor loop with custom delay (100ms)
mosquitto_pub -h <broker_ip> -t "arena/sparknode01/cmd" -m "sensor_loop start 100"

# Stop sensor data collection  
mosquitto_pub -h <broker_ip> -t "arena/sparknode01/cmd" -m "sensor_loop stop"

# Run sensor loop for exactly 100 iterations
mosquitto_pub -h <broker_ip> -t "arena/sparknode01/cmd" -m "sensor_loop counted 100"

# Start sensor streaming with default period
mosquitto_pub -h <broker_ip> -t "arena/sparknode01/cmd" -m "sensor_stream start"

# Start sensor streaming with 100ms period
mosquitto_pub -h <broker_ip> -t "arena/sparknode01/cmd" -m "sensor_stream start 100"

# Set sensor stream mode to magnetometer only
mosquitto_pub -h <broker_ip> -t "arena/sparknode01/cmd" -m "sensor_stream mode mag"

# Set sensor stream mode to accelerometer and gyroscope
mosquitto_pub -h <broker_ip> -t "arena/sparknode01/cmd" -m "sensor_stream mode accel_gyro"

# Stop sensor streaming
mosquitto_pub -h <broker_ip> -t "arena/sparknode01/cmd" -m "sensor_stream stop"

# Broadcast sensor start to all sparknodes
mosquitto_pub -h <broker_ip> -t "arena/all/cmd" -m "sensor_loop start"

# Subscribe to orientation data from a specific sparknode
mosquitto_sub -h <broker_ip> -t "arena/sparknode01/orientation"

# Subscribe to orientation data from all sparknodes
mosquitto_sub -h <broker_ip> -t "arena/+/orientation"

# Monitor both status and orientation data
mosquitto_sub -h <broker_ip> -t "arena/sparknode01/#"
```

### **IMU Calibration Examples**

```bash
# Recalibrate gyroscope (robot should be stationary during calibration)
mosquitto_pub -h <broker_ip> -t "arena/sparknode01/cmd" -m "calibrate gyro"

# Recalibrate magnetometer using 2D (flat rotation) calibration
mosquitto_pub -h <broker_ip> -t "arena/sparknode01/cmd" -m "calibrate mag hard"

# Recalibrate magnetometer using 3D (figure-8) calibration
mosquitto_pub -h <broker_ip> -t "arena/sparknode01/cmd" -m "calibrate mag soft"

# Capture raw magnetometer data for external calibration (default 500 samples, 50ms delay)
mosquitto_pub -h <broker_ip> -t "arena/sparknode01/cmd" -m "calibrate mag capture"

# Capture 800 magnetometer samples with 100ms delay
mosquitto_pub -h <broker_ip> -t "arena/sparknode01/cmd" -m "calibrate mag capture 800 100"

# Apply externally computed calibration (example values)
mosquitto_pub -h <broker_ip> -t "arena/sparknode01/cmd" -m "calibrate mag apply -12.5 8.3 -15.2 1.02 0.01 -0.02 0.01 0.98 0.03 -0.02 0.03 1.01 3"

# Broadcast gyro calibration to all sparknodes
mosquitto_pub -h <broker_ip> -t "arena/all/cmd" -m "calibrate gyro"

# Example of error handling for unsupported sensor type
mosquitto_pub -h <broker_ip> -t "arena/sparknode01/cmd" -m "calibrate accel"
# Response: "Unknown sensor type: accel (supported: gyro, mag)"
```

### **Navigation Examples**

```bash
# Show current heading without moving the robot (single sample)
mosquitto_pub -h <broker_ip> -t "arena/sparknode01/cmd" -m "show heading"

# Show average heading over 10 samples with 100ms delay
mosquitto_pub -h <broker_ip> -t "arena/sparknode01/cmd" -m "show heading 10 100"

# Show average heading over 5 samples with 200ms delay  
mosquitto_pub -h <broker_ip> -t "arena/sparknode01/cmd" -m "show heading 5 200"

# Turn to 90 degrees (east) using proportional control (default speed)
mosquitto_pub -h <broker_ip> -t "arena/sparknode01/cmd" -m "turn to 90"

# Turn to 180 degrees (south) with custom maximum speed
mosquitto_pub -h <broker_ip> -t "arena/sparknode01/cmd" -m "turn to 180 30"

# Rotate to 90 degrees (east) using default parameters
mosquitto_pub -h <broker_ip> -t "arena/sparknode01/cmd" -m "rotate to 90"

# Rotate to 180 degrees (south) with custom speed
mosquitto_pub -h <broker_ip> -t "arena/sparknode01/cmd" -m "rotate to 180 25"

# Rotate to 270 degrees (west) with full parameter control
mosquitto_pub -h <broker_ip> -t "arena/sparknode01/cmd" -m "rotate to 270 30 50 300 5.0"
# Parameters: target=270°, speed=30, step=50ms, delay=300ms, tolerance=5.0°

# Rotate to north (0 degrees) with custom speed
mosquitto_pub -h <broker_ip> -t "arena/sparknode01/cmd" -m "rotate to 0 20"

# Broadcast rotation command to all sparknodes
mosquitto_pub -h <broker_ip> -t "arena/all/cmd" -m "rotate to 90"
```

### **Scripted Command Sequences**

When sending multiple movement commands in a script, you **must wait** for each command to complete before sending the next one. Here is a complete example script:

```bash
#!/bin/bash
# SparkNode Sequential Movement Script
mqtt_broker="192.168.11.100"
sparknode="sparknode01"

echo "Starting movement sequence for $sparknode..."

# Show current configuration first
mosquitto_pub -h $mqtt_broker -t "arena/$sparknode/cmd" -m "config show"
sleep 2

echo "=== Movement Sequence ==="

# Drive forward for 5 seconds
echo "Driving forward..."
mosquitto_pub -h $mqtt_broker -t "arena/$sparknode/cmd" -m "drive forward 32 5000"
sleep 6  # Wait: 5 seconds (command duration) + 1 second (safety buffer)

# Turn right for 1 second
echo "Turning right..."
mosquitto_pub -h $mqtt_broker -t "arena/$sparknode/cmd" -m "turn right 30 1000"
sleep 2  # Wait: 1 second (command duration) + 1 second (safety buffer)

# Drive reverse for 3 seconds
echo "Driving reverse..."
mosquitto_pub -h $mqtt_broker -t "arena/$sparknode/cmd" -m "drive reverse 25 3000"
sleep 4  # Wait: 3 seconds (command duration) + 1 second (safety buffer)

# Turn left for 1.5 seconds
echo "Turning left..."
mosquitto_pub -h $mqtt_broker -t "arena/$sparknode/cmd" -m "turn left 30 1500"
sleep 3  # Wait: 1.5 seconds (command duration) + 1.5 seconds (safety buffer)

echo "Movement sequence complete!"

# Emergency stop example
# mosquitto_pub -h $mqtt_broker -t "arena/$sparknode/cmd" -m "stop"
```

**Sensor Data Collection Script Example**:

```bash
#!/bin/bash
# SparkNode Sensor Collection Script
mqtt_broker="192.168.11.100"
sparknode="sparknode01"

echo "Starting sensor data collection for $sparknode..."

# Start continuous sensor data collection
echo "Starting continuous sensor loop..."
mosquitto_pub -h $mqtt_broker -t "arena/$sparknode/cmd" -m "sensor_loop start"

# Let it run for 30 seconds
sleep 30

echo "Stopping sensor loop..."
mosquitto_pub -h $mqtt_broker -t "arena/$sparknode/cmd" -m "sensor_loop stop"

echo "Collecting 50 sensor samples..."
# Collect exactly 50 samples  
mosquitto_pub -h $mqtt_broker -t "arena/$sparknode/cmd" -m "sensor_loop counted 50"

# Wait for completion (allow sufficient time for samples to complete)
sleep 12

echo "Sensor collection complete!"

# Example: Subscribe and monitor orientation data
mosquitto_sub -h $mqtt_broker -t "arena/+/orientation" -v &
# Output will show messages like:
# arena/sparknode01/orientation {"yaw":85.32,"pitch":2.15,"roll":-1.03}
```

**Navigation Script Example**:

```bash
#!/bin/bash
# SparkNode Navigation Script - Rotate through cardinal directions
mqtt_broker="192.168.11.100"
sparknode="sparknode01"

echo "Starting navigation sequence for $sparknode..."

# Start continuous sensor data collection for heading feedback
mosquitto_pub -h $mqtt_broker -t "arena/$sparknode/cmd" -m "sensor_loop start"
sleep 2

# First, check current heading
echo "Checking current heading..."
mosquitto_pub -h $mqtt_broker -t "arena/$sparknode/cmd" -m "show heading"
sleep 2

echo "=== Navigation Sequence ==="

# Use "turn to" for smoother proportional control
# Turn to North (0 degrees)
echo "Turning to North (0°)..."
mosquitto_pub -h $mqtt_broker -t "arena/$sparknode/cmd" -m "turn to 0 25"
sleep 15  # Allow time for turn to complete

# Turn to East (90 degrees)
echo "Turning to East (90°)..."
mosquitto_pub -h $mqtt_broker -t "arena/$sparknode/cmd" -m "turn to 90 25"
sleep 15  # Allow time for turn to complete

# Turn to South (180 degrees) 
echo "Turning to South (180°)..."
mosquitto_pub -h $mqtt_broker -t "arena/$sparknode/cmd" -m "turn to 180 25"
sleep 15  # Allow time for turn to complete

# Turn to West (270 degrees)
echo "Turning to West (270°)..."
mosquitto_pub -h $mqtt_broker -t "arena/$sparknode/cmd" -m "turn to 270 25"
sleep 15  # Allow time for turn to complete

# Return to North
echo "Returning to North (0°)..."
mosquitto_pub -h $mqtt_broker -t "arena/$sparknode/cmd" -m "turn to 0 25"
sleep 15  # Allow time for turn to complete

# Final heading check
echo "Final heading check..."
mosquitto_pub -h $mqtt_broker -t "arena/$sparknode/cmd" -m "show heading"
sleep 2

echo "Navigation sequence complete!"

# Stop sensor loop
mosquitto_pub -h $mqtt_broker -t "arena/$sparknode/cmd" -m "sensor_loop stop"
```

**Alternative using "rotate to" for precise step control**:

```bash
#!/bin/bash
# SparkNode Precision Navigation Script - Using rotate to with precise parameters
mqtt_broker="192.168.11.100"
sparknode="sparknode01"

echo "Starting precision navigation sequence for $sparknode..."

# Start continuous sensor data collection for heading feedback
mosquitto_pub -h $mqtt_broker -t "arena/$sparknode/cmd" -m "sensor_loop start"
sleep 2

echo "=== Precision Navigation Sequence ==="

# Rotate to North (0 degrees) with custom parameters
echo "Rotating to North (0°)..."
mosquitto_pub -h $mqtt_broker -t "arena/$sparknode/cmd" -m "rotate to 0 15 10 300 5.0"
sleep 15  # Allow time for rotation to complete

# Rotate to East (90 degrees)
echo "Rotating to East (90°)..."
mosquitto_pub -h $mqtt_broker -t "arena/$sparknode/cmd" -m "rotate to 90 15 10 300 5.0"
sleep 15  # Allow time for rotation to complete

# Rotate to South (180 degrees) 
echo "Rotating to South (180°)..."
mosquitto_pub -h $mqtt_broker -t "arena/$sparknode/cmd" -m "rotate to 180 15 10 300 5.0"
sleep 15  # Allow time for rotation to complete

# Rotate to West (270 degrees)
echo "Rotating to West (270°)..."
mosquitto_pub -h $mqtt_broker -t "arena/$sparknode/cmd" -m "rotate to 270 15 10 300 5.0"
sleep 15  # Allow time for rotation to complete

# Return to North
echo "Returning to North (0°)..."
mosquitto_pub -h $mqtt_broker -t "arena/$sparknode/cmd" -m "rotate to 0 15 10 300 5.0"
sleep 15  # Allow time for rotation to complete

echo "Precision navigation sequence complete!"

# Stop sensor loop
mosquitto_pub -h $mqtt_broker -t "arena/$sparknode/cmd" -m "sensor_loop stop"
```

**⚠️ Critical Timing Rule**: 
```bash
# For each movement command: sleep (command_duration_ms/1000 + safety_buffer)
mosquitto_pub -h $broker -t "arena/sparknode01/cmd" -m "drive forward 32 5000"
sleep 6  # 5 seconds (movement) + 1 second (safety buffer)

# For rotate to commands: allow ~10-15 seconds depending on angle difference and parameters
mosquitto_pub -h $broker -t "arena/sparknode01/cmd" -m "rotate to 90 15 10 300 5.0"
sleep 15  # Allow time for magnetometer-based rotation to complete

# For turn to commands: allow ~15-30 seconds depending on angle difference
mosquitto_pub -h $broker -t "arena/sparknode01/cmd" -m "turn to 90 25"
sleep 15  # Allow time for proportional turn control to complete
```

## Implementation Notes

-   **Non-blocking**: Drive/turn commands spawn tasks, so multiple commands can
    be queued
-   **Motor control**: Uses the DRV8830 dual motor driver with a configurable
    kick-start mechanism
-   **IMU integration**: ICM-20948 9-DOF sensor with gyroscope and magnetometer calibration
-   **Sensor control**: Provides real-time control of IMU sensor data collection and processing loops
-   **Persistent calibration**: IMU calibration data is stored in NVS for consistent performance across reboots
-   **Magnetometer navigation**: Implements closed-loop heading control using a calibrated magnetometer with automatic correction
-   **Error handling**: Publishes status on successful parsing; unknown commands
    receive help text
-   **Safety**: The stop command provides immediate motor shutdown capability
-   **Static friction compensation**: Automatic kick-start ensures reliable
    motor startup
-   **Individual motor calibration**: Provides left/right wheel speed compensation for
    straight-line accuracy
-   **Fleet management**: Each SparkNode can be optimized for its specific motor
    and sensor characteristics

## Per-SparkNode Configuration

The system supports individual configuration for each SparkNode to handle motor
manufacturing variations:

**Configuration Parameters**:

-   **Drive kick**: Initial torque pulse for straight movement (speed and
    duration)
-   **Turn kick**: Initial torque pulse for turning (usually stronger than the drive
    kick)
-   **Wheel calibration**: Speed correction factors to compensate for motor
    differences
-   **Default speed**: Fallback speed when not specified in commands

**Usage Strategy**:

-   **Well-broken-in SparkNodes**: Use gentler kick parameters (lower
    speed and shorter duration)
-   **New/stubborn SparkNodes**: Use stronger kicks for reliable startup
-   **Motor matching**: Use wheel calibration factors to ensure straight movement
    despite motor variations
-   **Fleet optimization**: Test and configure each robot individually for optimal
    performance

## Appendix A: MQTT System

We use a Raspberry Pi 5 as the broker (TODO: network diagram). Here are the
installation notes:

``` bash
sudo apt update
sudo apt install mosquitto mosquitto-clients -y
```

where `mosquitto` is the broker (server) and `mosquitto-clients` are
command-line tools for publishing and subscribing (useful for testing).

Check that the configuration file `/etc/mosquitto/mosquitto.conf` has the proper
entries:

```
    # Place your local configuration in /etc/mosquitto/conf.d/
    #
    # A full description of the configuration file is at
    # /usr/share/doc/mosquitto/examples/mosquitto.conf.example

    pid_file /run/mosquitto/mosquitto.pid

    persistence true
    persistence_location /var/lib/mosquitto/

    log_dest file /var/log/mosquitto/mosquitto.log

    include_dir /etc/mosquitto/conf.d

    listener 1883 0.0.0.0
    allow_anonymous true
```
After the installation, start running the server:

``` bash
sudo systemctl enable mosquitto
sudo systemctl start mosquitto
```

Check that it is running:

``` bash
sudo systemctl status mosquitto
```

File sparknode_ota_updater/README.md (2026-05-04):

# SparkNode Over-The-Air (OTA) Firmware Updater
## Overview

When the chip is programmed for the very first time, we flash `sparknode_ota_updater` in the `factory` partition via a USB connection. 

 Then, whenever the chip is rebooted, or power-cycled, it downloads a binary file and its corresponding MD5 checksum from the server specified in `network_config.h`. If the download is successful, the binary is written to the `ota_0` partition, the boot partition is set to `ota_0`, and the chip is restarted.

On subsequent boots, if the downloaded binary is properly configured (see `sparknode_sample_ota_app`[^1] for an example), the application changes the boot partition to `factory` to check the availability of updated firmware by running `sparknode_ota_updater` at every restart. 

Key Features are
- **Smart Checksum Caching**: Prevents unnecessary downloads
- **Robust Retry Logic**: 3-attempt mechanism for network failures  
- **Network Failure Fallback**: Boots existing firmware when remote access fails
- **Boot Partition Management**: Intelligent switching between factory and OTA partitions
- **Visual Status Indicators**: LED feedback for operation status
- **Remote Logging**: UDP-based debugging capabilities

[^1] The relevant code block is:
```
#ifdef OTA_UPDATE_ENABLED
    ESP_LOGI(TAG, "OTA update enabled");
    set_next_boot_to_factory();
#endif // OTA_UPDATE_ENABLED
```  
## ESP32-CAM and ESP-IDF Configuration

Configuration details (including the partition table) are in 
the main [README.md](../README.md) file of the **SyncSpark** project.

## Software Configuration Before the First Compilation 

Configuration details (including the partition table) are in 
the main [README.md](../README.md) file of the **SyncSpark** project.

## Required ESP-IDF Components

- led_strip, run this command:
```bash
   idf.py add-dependency "espressif/led_strip^3.0.0"
```
## Operational Details

### Main Algorithm

```
Algorithm 1: SparkNode OTA Updater Main Process
Input: WiFi credentials, HTTP server configuration
Output: Firmware updated and device rebooted to correct partition

1: procedure OTAUpdater()
2:    Initialize system (NVS, LEDs, WiFi, UDP logging)
3:    sparknode_id ← GetSparkNodeID()
4:    
5:    ▷ Phase 1: Fetch Remote Checksum
6:    for attempt = 1 to 3 do
7:        Fetch remote MD5 checksum from HTTP server
8:        if checksum fetched successfully AND length = 32 then
9:            break
10:       else
11:           Indicate error and continue
12:       end if
13:   end for
14:   
15:   ▷ Phase 1.5: Network Failure Fallback
16:   if checksum fetch failed after 3 attempts then
17:       stored_checksum ← RetrieveFromNVS("checksum")
18:       if stored_checksum exists then
19:           Log "Network issues detected, booting existing firmware"
20:           SetBootPartition(ota_0)
21:           IndicateSuccess()
22:           Restart()  ▷ Boot with existing firmware
23:       else
24:           Log "No stored checksum and unable to fetch remote"
25:           IndicateFailure()
26:           return
27:       end if
28:   end if
29:   
30:   ▷ Phase 2: Smart Caching Logic  
31:   stored_checksum ← RetrieveFromNVS("checksum") ▷ Only if not already retrieved
32:   if stored_checksum exists then
33:       if stored_checksum = remote_checksum then
34:           Log "No update needed, booting existing app"
35:           SetBootPartition(ota_0)
36:           IndicateSuccess()
37:           Restart()
38:       else
39:           Log "Update needed - checksums differ"
40:       end if
41:   else
42:       Log "No stored checksum - first time update"
43:   end if
33:   
34:   ▷ Phase 3: Download and Verify Firmware
35:   firmware_updated ← DownloadAndVerifyFirmware(remote_checksum)
36:   if firmware_updated = FALSE then
37:       IndicateFailure()
38:       return
39:   end if
40:   
41:   ▷ Phase 4: Complete OTA Process
42:   StoreInNVS("checksum", remote_checksum)
43:   SetBootPartition(ota_0)
44:   IndicateSuccess()
45:   Restart()
46: end procedure
```
### Sub-Algorithms

#### Fetch Remote Checksum with Retry

```
Algorithm 2: FetchRemoteChecksum
Input: url, maxAttempts = 3
Output: checksum string or NULL

1: function FetchRemoteChecksum(url, maxAttempts)
2:     for attempt = 1 to maxAttempts do
3:         Log attempt number
4:         result ← HTTP_GET(url)
5:         if result = SUCCESS then
6:             if checksum.length = 32 then
7:                 BlinkFlashLED(success_pattern)
8:                 return checksum
9:             else
10:                Log "Invalid checksum length"
11:                IndicateError()
12:            end if
13:        else
14:            Log "HTTP request failed"
15:            IndicateError()
16:        end if
17:    end for
18:    Log "Failed after all attempts"
19:    ▷ Main algorithm handles fallback to existing firmware
20:    return NULL
21: end function
```

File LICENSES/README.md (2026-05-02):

# License Overview

This directory contains the license texts used by this repository.

- [GPL-3.0.txt](./GPL-3.0.txt): applies to the repository's software source
  code, unless a file or subdirectory states otherwise.
- [CERN-OHL-S-2.0.txt](./CERN-OHL-S-2.0.txt): applies to hardware design
  materials under [../docs/hardware](../docs/hardware), unless a file or
  subdirectory states otherwise.

For a higher-level summary, see the licensing section in
[../README.md](../README.md).

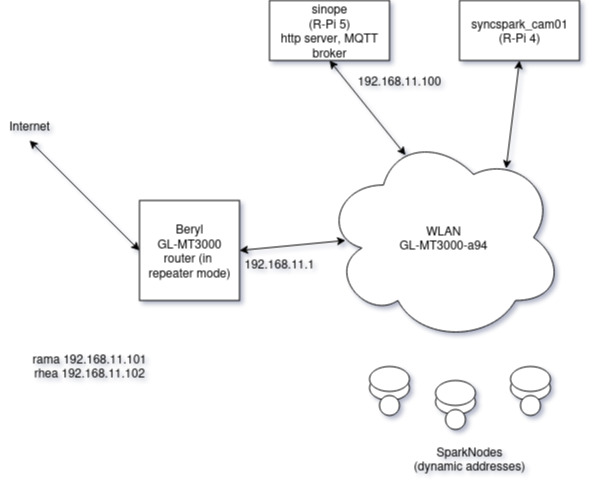
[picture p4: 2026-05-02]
docs/system/beryl_network.jpg

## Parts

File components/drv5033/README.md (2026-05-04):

# TLI4906 Hall Sensor Component

A comprehensive ESP32 component for TLI4906 hall effect sensor-based wheel turn counting and motion detection.

## Features

This component provides interrupt-driven hall sensor functionality for accurate wheel rotation measurement using two TLI4906 hall effect sensors:
- **Sensor 1 (Left wheel)**: Detects magnets attached to left wheel for tracking rotation
- **Sensor 2 (Right wheel)**: Detects magnets attached to right wheel for tracking rotation

## Key Functions

### Initialization and Setup
- `initialize_hall_sensors(const hall_sensor_config_t *config)` - Sets up GPIO interrupts for both sensors
- `deinitialize_hall_sensors(void)` - Clean up resources and remove interrupts

### Data Access
- `get_sensor_count(hall_sensor_id_t sensor_id)` - Returns total pulse count for specified sensor (SENSOR_1 or SENSOR_2)
- `get_time_since_last_pulse_us(hall_sensor_id_t sensor_id)` - Time since last pulse in microseconds, -1 if no pulse detected yet
- `get_sensor_states(bool *sensor_1_state, bool *sensor_2_state)` - Get current raw sensor states (for debugging)

### Motion Calculations
- `calculate_wheel_revolutions(hall_sensor_id_t sensor_id)` - Calculates complete wheel turns for specified wheel
- `calculate_wheel_angle_degrees(hall_sensor_id_t sensor_id)` - Current angle within revolution (0-360°) for specified wheel
- `calculate_wheel_rpm(hall_sensor_id_t sensor_id, uint32_t time_window_ms)` - Estimated RPM based on recent pulse timing
- `is_wheel_moving(hall_sensor_id_t sensor_id, uint32_t threshold_ms)` - Detects if specified wheel is currently rotating

### Utility Functions
- `reset_sensor_counts(void)` - Reset all counters to zero
- `wait_for_sensor_2_pulse(uint32_t timeout_ms)` - Blocking wait for next sensor 2 pulse

## Configuration

### Default Configuration
The component uses the following default settings:
```c
#define HALL_SENSOR_DEFAULT_MAGNETS_PER_REV    4
#define HALL_SENSOR_DEFAULT_DEBOUNCE_US        1000
#define HALL_SENSOR_DEFAULT_INVERT_LOGIC       false
```

### GPIO Setup
Configure your GPIO pins in `syncspark_config.h`:
```c
#define LEFT_WHEEL_SENSOR   GPIO_NUM_13  // Left wheel sensor (multiple magnets)
#define RIGHT_WHEEL_SENSOR  GPIO_NUM_14  // Right wheel sensor (multiple magnets)
```

### Sensor Logic
- **Default behavior**: Hall sensors are HIGH when no magnet is present, LOW when magnet is detected
- **Configurable**: Set `invert_logic = true` if your sensors work oppositely
- **Pull-up**: Component automatically enables GPIO pull-up resistors

## Usage Example

### Basic Initialization
```c
#include "tli4906.h"

// Create separate configurations for each sensor
hall_sensor_config_t sensor_1_config = HALL_SENSOR_DEFAULT_CONFIG(GPIO_NUM_13);
hall_sensor_config_t sensor_2_config = HALL_SENSOR_DEFAULT_CONFIG(GPIO_NUM_14);

// Initialize with both configurations
esp_err_t result = initialize_hall_sensors(&sensor_1_config, &sensor_2_config);

if (result == ESP_OK) {
    ESP_LOGI("MAIN", "Hall sensors initialized successfully");
} else {
    ESP_LOGE("MAIN", "Failed to initialize hall sensors: %s", esp_err_to_name(result));
}
```

### Custom Configuration
```c
// Configure left wheel sensor (sensor 1) with 16 magnets
hall_sensor_config_t sensor_1_config = {
    .sensor_gpio = GPIO_NUM_13,
    .magnets_per_revolution = 16,    // 16 magnets on left wheel
    .invert_logic = false,           // Magnet detected = LOW
    .debounce_time_us = 500          // 500μs debounce time
};

// Configure right wheel sensor (sensor 2) with 8 magnets
hall_sensor_config_t sensor_2_config = {
    .sensor_gpio = GPIO_NUM_14,
    .magnets_per_revolution = 8,     // 8 magnets on right wheel
    .invert_logic = false,
    .debounce_time_us = 500
};

initialize_hall_sensors(&sensor_1_config, &sensor_2_config);
```

### Reading Data
```c
// Get current counts for each wheel
uint32_t left_wheel_pulses = get_sensor_count(SENSOR_1);
uint32_t right_wheel_pulses = get_sensor_count(SENSOR_2);

// Calculate motion for left wheel
float left_revolutions = calculate_wheel_revolutions(SENSOR_1);
float left_angle = calculate_wheel_angle_degrees(SENSOR_1);
float left_rpm = calculate_wheel_rpm(SENSOR_1, 5000);  // RPM over last 5 seconds
bool left_moving = is_wheel_moving(SENSOR_1, 2000);    // No pulse for 2+ seconds = stopped

// Calculate motion for right wheel
float right_revolutions = calculate_wheel_revolutions(SENSOR_2);
float right_angle = calculate_wheel_angle_degrees(SENSOR_2);
float right_rpm = calculate_wheel_rpm(SENSOR_2, 5000);
bool right_moving = is_wheel_moving(SENSOR_2, 2000);

ESP_LOGI("HALL", "Left: %lu pulses, %.2f rev, %.1f°, %.1f RPM, Moving: %s",
         left_wheel_pulses, left_revolutions, left_angle, left_rpm,
         left_moving ? "Yes" : "No");
         
ESP_LOGI("HALL", "Right: %lu pulses, %.2f rev, %.1f°, %.1f RPM, Moving: %s",
         right_wheel_pulses, right_revolutions, right_angle, right_rpm,
         right_moving ? "Yes" : "No");
```

### Reset Counters
```c
// Reset all counters to zero
reset_sensor_counts();
```

## Integration

### CMakeLists.txt
The component is configured with:
```cmake
idf_component_register(SRCS "src/tli4906.c"
                    INCLUDE_DIRS "include"
                    REQUIRES "driver" "esp_timer")
```

### Component Dependencies
The component requires:
- `driver` (for GPIO functions)
- `esp_timer` (for timing functions)
- `freertos` (for mutex and tasks)

## Technical Details

### Interrupt Handling
- Uses GPIO interrupts on falling edges (NEGEDGE)
- Interrupt handlers run in IRAM for fast response
- Built-in debouncing prevents false triggers from mechanical noise
- Thread-safe with mutex protection for shared data

### Timing Accuracy
- Uses `esp_timer_get_time()` for microsecond precision
- Calculates RPM based on time between consecutive pulses
- Tracks last pulse times for motion detection

### Memory Usage
- Minimal RAM footprint with single global data structure
- No dynamic memory allocation during operation
- Interrupt handlers optimized for speed

## Hardware Requirements

### TLI4906 Hall Sensors
- Digital hall effect sensors (TLI4906 or compatible)
- Output: HIGH when no magnet is present, LOW when magnet is detected
- Connect to 3.3V power and any available GPIO pins

### Magnets
- Small neodymium magnets mounted on each wheel
- Default configuration: 4 magnets per wheel (configurable)
- Magnets should be evenly spaced around the wheel circumference

### Wiring
```
TLI4906 VCC → ESP32 3.3V
TLI4906 GND → ESP32 GND  
TLI4906 OUT → ESP32 GPIO (with internal pull-up enabled)
```

Connect one TLI4906 sensor near the left wheel and another near the right wheel, with magnets attached to each wheel.

## Troubleshooting

### No Pulse Detection
- Check magnet placement and polarity
- Verify GPIO pin configuration in your code
- Ensure TLI4906 sensors are powered correctly (3.3V)
- Check wiring connections
- Verify magnets are close enough to sensors (typically < 5mm)

### False Triggers
- Increase debounce time (`debounce_time_us`)
- Check for electromagnetic interference
- Ensure stable power supply to sensors
- Verify magnet strength and positioning

### Inaccurate Counts
- Verify `magnets_per_revolution` setting matches actual magnet count
- Check for missed interrupts (reduce other interrupt load)
- Ensure magnets are evenly spaced on wheels
- Consider mechanical vibration effects
- Verify sensor mounting is secure

### Different Behavior per Wheel
- Each wheel can be monitored independently using SENSOR_1 and SENSOR_2
- Verify each sensor's GPIO configuration
- Check that magnets on both wheels are properly positioned

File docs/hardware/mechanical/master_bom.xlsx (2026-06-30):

Status | Board | Item Name | Per SparkNode Quantity | Total Quantity Needed | Quantity We Have in Stock | Unit Price (A$) | Cost (A$) | Remarks | Manufacturer Part | Manufacturer | Supplier | Supplier Part | Link
 | Circle | Circle board with SMT components pre-assembled | 1 | 5 |  | $16.00 | $80.00 | Ismet’s design |  | JLCPCB
 | Back | Backboard PCB | 1 | 5 |  | $3.00 | $15.00 | Ismet’s design |  | JLCPCB
 | Body | Hall-effect sensor board (for wheel rotation counting) | 1 | 5 |  | $3.00 | $15.00 | Ismet’s design
 | Body | Dagu DG01D 48:1 motor (sold in pairs) | 1 | 5 |  | $10.00 | $50.00 |  |  | Dagu | Core Electronics |  | https://core-electronics.com.au/hobby-gearmotor-140-rpm-pair.html
 | Circle | GY-912 IMU module | 1 | 5 |  | $17.49 | $87.45 |  |  |  | Ali Express |  | https://www.aliexpress.com/item/1005006894756676.html
 | Body | Robot chassis and wheels | 1 | 5 |  | $4.70 | $23.50 |  |  |  | Ali Express |  | https://www.aliexpress.com/item/1005009043311098.html
 | Body | Ball castor wheels | 2 | 10 |  | $0.75 | $7.50 |  |  |  | Ali Express |  | https://www.aliexpress.com/item/1005009290683513.html
 | Body | Battery set | 1 | 5 |  | $20.00 | $100.00 | Li-Ion AA batteries |  |  | Ali Express |  | We will test 21700 batteries, and switch to 21700 if our circuit works well. Otherwise we will continue using eneloops
Check numbers | Body | Contact, WR-WTB, Socket, Crimp, 22 AWG, 28 AWG | 39 | 195 |  | $0.25 | $48.75 |  | 61900113722DEC | WURTH | Element14 | 1841425 | https://au.element14.com/wurth-elektronik/61900113722dec/contact-2-54mm-crimp-awg28-22/dp/1841425?ost=1841425
Do not order | Circle | ESP-32 Cam AI-Thinker module | 1 | 5 | 20 | $13.00 | $65.00 |  |  |  | Ali Express |  | https://www.aliexpress.com/item/1005006097541310.html
Do not order | Circle | #2870 5V Step-Up/Step-Down Voltage Regulator w/ Adjustable Low-Voltage Cutoff S9V11F5S6CMA | 1 | 5 | 7 | $17.14 | $85.70 |  | S9V11F5S6CMA | Pololu | Core Electronics |  | https://core-electronics.com.au/5v-step-up-step-down-voltage-regulator-w-adjustable-low-voltage-cutoff-s9v11f5s6cma.html
Do not order | Circle | Slide Switch | 1 | 5 | 16 | $1.72 | $8.60 |  | MFS101D-8-Z | NIDEC COMPONENTS | Element14 | 563-1556-ND | https://au.element14.com/nidec-copal/mfs101d-8-z/slide-switch-spdt-2a-30vac-th/dp/2854844
Do not order | Circle | Fuse, Cartridge, Fast Acting, 1.6 A, 250 V, 5mm x 20mm, 0.2" x 0.79", FSF | 1 | 5 | 27 | $0.51 | $2.54 |  | 0034.1518 | SCHURTER | Element14 | 1360787 | https://au.element14.com/schurter/0034-1518/fuse-fast-acting-glass-1-6a/dp/1360787
Do not order | Circle | HDR-TH_2P-P2.54-V-R1-C2-FEMALE HOUSING | 6 | 30 | 125 | $0.13 | $3.93 |  | 2212S-02SG-85 | MULTICOMP | Element14 | 1593458 | https://au.element14.com/multicomp-pro/2212s-02sg-85/receptacle-tht-vertical-2-54mm/dp/1593458
Do not order | Circle | HDR-TH_4P-P2.54-V-R1-C4-FEMALE HOUSING | 3 | 15 | 73 | $0.29 | $4.30 |  | 2212S-04SG-85 | MULTICOMP | Element14 | 1593460 | https://au.element14.com/multicomp/2212s-04sg-85/socket-pcb-1-row-4way/dp/1593460?ost=1593460
Do not order | Circle | HDR-TH_5P-P2.54-V-R1-C5 FEMALE HOUSING | 1 | 5 | 27 | $0.27 | $1.35 |  | 2212S-05SG-85 | MULTICOMP | Element14 | 1593461 | https://au.element14.com/multicomp-pro/2212s-05sg-85/socket-pcb-1-row-5way/dp/1593461
 | Circle, Back | HDR-TH_8P-P2.54-V-R1-C8-FEMALE HOUSING | 3 | 15 | 58 | $0.34 | $5.03 |  | 2212S-08SG-85 | MULTICOMP | Element14 | 1593463 | https://au.element14.com/multicomp-pro/2212s-08sg-85/socket-pcb-1-row-8way/dp/1593463?ost=1593463
 | Circle | CONN PCB MALE 2 X 2.54MM PIN BOTTOM LOCKING RIGHT ANGLE HEADER | 3 | 15 | 40 | $0.74 | $11.14 |  | 61900211021 | WURTH | Element14 | 1841368 | https://au.element14.com/wurth-elektronik/61900211021/header-2-54mm-r-a-b-locking-2way/dp/1841368?ost=1841368
 | Circle | CONN_HDR_MALE_PIN_2.54_LOCKING_VERTICAL_R1_C2 | 2 | 10 | 31 | $0.88 | $8.80 |  | 61900211121 | WURTH | Element14 | 1841369 | https://au.element14.com/wurth-elektronik/61900211121/header-2-54mm-locking-2way/dp/1841369
 | Body | Connector Housing, WR-WTB, Receptacle, 2 Ways, 2.54 mm | 5 | 25 | 183 | $0.22 | $5.58 |  | 61900211621 | WURTH | Element14 | 1841370 | https://au.element14.com/wurth-elektronik/61900211621/housing-2-54mm-2way/dp/1841370?ost=1841370
 | Sensor, Back | CONN PCB MALE 4 X 2.54MM PIN VERTICAL LOCKING HEADER | 2 | 10 | 52 | $1.46 | $14.60 |  | 61900411121 | WURTH | Element14 | 1841378 | https://au.element14.com/wurth-elektronik/61900411121/header-2-54mm-locking-4way/dp/1841378?ost=1841378
 | Body | Connector Housing, WR-WTB, Receptacle, 4 Ways, 2.54 mm | 2 | 10 | 400 | $0.30 | $2.96 |  | 61900411621 | WURTH | Element14 | 1841379 | https://au.element14.com/wurth-elektronik/61900411621/housing-2-54mm-4way/dp/1841379?ost=1841379
 | Back | CONN PCB MALE 5 X 2.54MM PIN VERTICAL LOCKING HEADER | 1 | 5 | 21 | $1.91 | $9.55 |  | 61900511121 | WURTH | Element14 | 1841382 | https://au.element14.com/wurth-elektronik/61900511121/header-2-54mm-locking-5way/dp/1841382?ost=1841382
 | Body | Connector Housing, WR-WTB, Receptacle, 5 Ways, 2.54 mm | 1 | 5 | 200 | $0.29 | $1.45 |  | 61900511621 | WURTH | Element14 | 1841383 | https://au.element14.com/wurth-elektronik/61900511621/housing-2-54mm-5way/dp/1841383?ost=1841383
 | Circle, Back | CONN PCB MALE 8 X 2.54MM PIN BOTTOM LOCKING RIGHT ANGLE HEADER | 2 | 10 | 37 | $1.13 | $11.30 |  | 61900811021 | WURTH | Element14 | 3818035 | https://au.element14.com/wurth-elektronik/61900811021/conn-r-a-header-8pos-1row-2-54mm/dp/3818035
 | Body | Connector Housing, WR-WTB, Receptacle, 8 Ways, 2.54 mm | 2 | 10 | 54 | $0.51 | $5.12 |  | 61900811621 | WURTH | Element14 | 3818418 | https://au.element14.com/wurth-elektronik/61900811621/connector-housing-rcpt-8pos-2/dp/3818418?ost=3818418
 | Back | SWITCH TACT 6MMX6MM | 1 | 5 | 24 | $0.22 | $1.10 |  | MCDTS6-1K | MULTICOMP | Element14 | 947167701 | https://au.element14.com/multicomp-pro/mcdts6-1k/tactile-switch-4-3mm-100g/dp/9471677?ost=mcdts6-1k
 | Sensor | TEST POINT 1.6MM 1MM | 3 | 15 |  | $0.19 | $2.79 | minimum order 10 |  |  | Element14 |  | https://au.element14.com/multicomp/test-1-bk/test-pin-pcb-black-pk100/dp/1702000
 | Circle | FUSE HOLDER-TH-20MMX5MM | 2 | 10 | 30 | $0.18 | $1.80 | minimum order 10 | 7510110 | SCHURTER | Element14 | 1453528 | https://au.element14.com/schurter/0751-0110/fuse-clip-5x20mm-pcb-mount/dp/1453528
 | Circle | Minimoto motor driver DRV 8830 module | 2 | 10 | 21 | $5.05 | $50.50 |  |  |  | Ali Express |  | https://www.aliexpress.com/item/32811501311.html
 | Back | LED light pipe | 1 | 5 | 14 | $0.05 | $0.25
 | Back | CAP CER 100n 2.5MM | 1 | 5 |  | $0.18 | $0.90 |  | K104Z15Y5VE5TL2 | VISHAY | Element14 | 3322180 | https://au.element14.com/vishay/k104z15y5ve5tl2/bc-components-part-number/dp/3322180
 | Sensor | DRV5033AJQLPGM hall-effect sensor | 2 | 10 | 98 | $0.18 | $1.80 | Omnipolar hall-effect switch
 | Sensor | 4.7nf | 4 | 20 |  | $0.18 | $3.60 |  | K104Z15Y5VE5TL2 | VISHAY | Element14 | K104Z15Y5VE5TL2 | https://au.element14.com/vishay/k104z15y5ve5tl2/cap-0-1uf-25v-mlcc-radial/dp/3289392
 | Back | CAP ELEC 10u | 1 | 5 |  | $0.18 | $0.90
 | Sensor | 200 resistor | 2 | 10 |  | $0.00 | $0.00
 | Sensor | 1.2K resistor | 2 | 10 |  | $0.00 | $0.00
 | Body | M3 phillips head screw 10 mm | 12 | 60 |  | $0.00 | $0.00 | For fixing the castor wheel base and circle board to the battery holder base
 | Body | M3 counter sunk head screw 10 mm | 4 | 20 |  |  |  | For fixing the battery holder base to the acrylic chassis
 | Body | M3 phillips head screw 16 mm | 4 | 20 |  |  |  | For fixing the SPL SparkNode esp32-cam base
 | Body | M3 hex nut | 20 | 100
 | Body | M3 flat washer | 20 | 100
 | Body | M3 internal shakeproof washer | 20 | 100
 | Body | AA battery spring contact | 3 | 15 | 9 |  |  |  |  |  | Ali Express
 | Body | AA battery leaf contact | 1 | 5 | 19 |  |  |  |  |  | Ali Express
 | Body | AA battery leaf + spring dual contact (spring at the right) | 1 | 5 | 19 |  |  |  |  |  | Ali Express
 | Body | Various 3D printed parts | (details coming soon) |  |  | $0.00 | $0.00 |  |  |  |  |  | We will print them at the department’s 3D printers
 |  | number of boards |  | 5
 |  | Total |  |  |  |  | $737.79
 |  | per sparknode cost (if we order 5 PCBs) |  |  |  |  | $147.56

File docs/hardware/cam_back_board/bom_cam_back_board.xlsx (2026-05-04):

ID | Name | Designator | Quantity | Manufacturer Part | Manufacturer | Supplier | Supplier Part | Remarks
1 | CONN PCB MALE 8 X 2.54MM PIN BOTTOM LOCKING RIGHT ANGLE HEADER | CN3 | 1 | 61900811021 | WURTH | Element14 | 3818035
2 | CAP CER 100n 2.5MM | C1,C3 | 2 | K104Z15Y5VE5TL2 | VISHAY | Element14 | 3289392
3 | CAP ELEC 10u | C2 | 1 | ECEA1CKS100 | Panasonic | Element14 | 1901997
4 | HDR-TH_8P-P2.54-V-R1-C8-FEMALE HOUSING | CN1,CN2 | 2 | 2211S-08SG-85 | MULTICOMP | Element14 | 1593463
5 | 1K | R1 | 1
6 | 1N4148TR | D1 | 1 | 1N4148TR | onsemi(安森美) | LCSC | C84410
7 | BC547B | Q1 | 1 | BC547B | LGE(鲁光) | LCSC | C713613
8 | 100K | R2 | 1
9 | SWITCH TACT 6MMX6MM | SW1 | 1 | MCDTS6-1K | MULTICOMP PRO | Element14 | 947167701
10 | CONN PCB MALE 5 X 2.54MM PIN VERTICAL LOCKING HEADER | CN5 | 1 | 61900411121 | WURTH | Element14 | 1841378
11 | CONN PCB MALE 4 X 2.54MM PIN VERTICAL LOCKING HEADER | CN4 | 1 | 61900411121 | WURTH | Element14 | 1841378

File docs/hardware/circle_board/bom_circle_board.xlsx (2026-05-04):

ID | Name | Designator | Quantity | Manufacturer Part | Manufacturer | Supplier | Supplier Part
1 | 0.1u | C1,C2,C3,C4,C5,C6,C7,C8,C9,C10,C11,C12,C13,C14,C15,C16 | 16 | K104Z15Y5VE5TL2 | VISHAY | Element14 | 3322180
2 | CONN_HDR_MALE_PIN_2.54_LOCKING_VERTICAL_R1_C2 | CN1,CN2 | 2 | 61900211121 | WURTH | Element14 | 1841369
3 | CONN PCB MALE 8 X 2.54MM PIN BOTTOM LOCKING RIGHT ANGLE HEADER | CN3 | 1 | 61900811021 | WURTH | Element14 | 3818035
4 | HDR-TH_5P-P2.54-V-R1-C5 FEMALE HOUSING | CN4 | 1 | 2212S-05SG-85 | MULTICOMP | Element14 | 1593461
5 | HDR-TH_2P-P2.54-V-R1-C2-FEMALE HOUSING | CN5,CN7,CN9,CN11,CN13,CN15 | 6 | 2212S-02SG-85 | MULTICOMP | Element14 | 1593458
6 | HDR-TH_4P-P2.54-V-R1-C4-FEMALE HOUSING | CN6,CN10,CN14 | 3 | 2212S-04SG-85 | MULTICOMP | Element14 | 1593460
7 | CONN PCB MALE 2 X 2.54MM PIN BOTTOM LOCKING RIGHT ANGLE HEADER | CN8,CN12,CN16 | 3 | 61900211021 | WURTH | Element14 | 1841368
8 | HDR-TH_8P-P2.54-V-R1-C8-FEMALE HOUSING | CN17 | 1 | 2212S-08SG-85 | MULTICOMP | Element14 | 1593463
9 | WS2812B RGB LED | D0,D1,D2,D3,D4,D5,D6,D7,D8,D9,D10,D11,D12,D13,D14,D15 | 16 | WS2812B | Worldsemi
10 | DIODE LED RED 3MM | D16,D17,D18,D19 | 4
11 | FUSE HOLDER-TH-20MMX5MM | FH1 | 1 | 7510110 | SCHURTER | Element14 | 1453528
12 | BSS138 | Q1,Q2,Q3 | 3 | BSS138 | ONSEMI | Element14 | 9845330
13 | 1K | R1,R8,R9,R10 | 4
14 | 10K | R2,R3,R4,R5,R6,R7 | 6
15 | Slide Switch | SW1 | 1 | MFS101D-8-Z | NIDEC COMPONENTS | Digi-Key | 563-1556-ND
16 | SWITCH TACT 6MMX6MM | SW2 | 1 | MCDTS6-1K | MULTICOMP PRO | Element14 | 947167701
17 | GND | TP1,TP5 | 2
18 | 5V | TP2 | 1
19 | SCL | TP3 | 1
20 | SDA | TP4 | 1
21 | RGB LED OUT | TP6 | 1
22 | 3.3V | TP7 | 1
23 | VBat | TP8 | 1
24 | Vcharge | TP9 | 1
25 | RGB LED IN | TP10 | 1

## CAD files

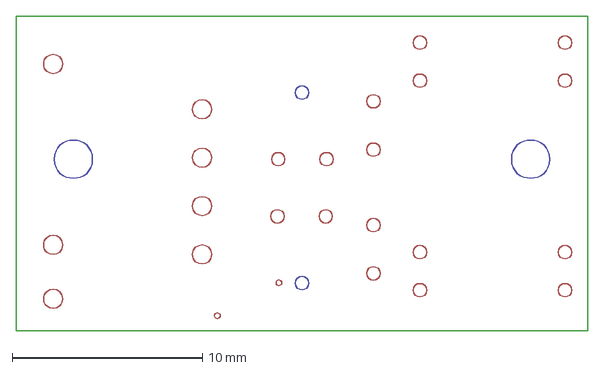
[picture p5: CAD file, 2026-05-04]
docs/hardware/sensor_board/pcb_holes_and_borders_sensor_board.dxf
30.0 x 16.5 mm

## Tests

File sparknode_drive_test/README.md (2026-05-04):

# SparkNode Motor Drive Tests
## Overview

This program is for testing the motor drive algorithms.

## ESP32-CAM and ESP-IDF Configuration

Configuration details (including the partition tabl) are in 
the main [README.md](../README.md) file of the **SyncSpark** project.

## Required Components

1. espressif/led_strip: `idf.py add-dependency "espressif/led_strip^3.0.0"`

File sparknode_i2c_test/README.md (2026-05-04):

# SparkNode I2C and RGB LED Ring Tests
## Overview

This program is for testing the operation of motor controllers, IMU (GY-912) and the RGB LED ring. 

## ESP32-CAM and ESP-IDF Configuration

Configuration details (including the partition tabl) are in 
the main [README.md](../README.md) file of the **SyncSpark** project.

## Required Components

1. espressif/led_strip: `idf.py add-dependency "espressif/led_strip^3.0.0"`

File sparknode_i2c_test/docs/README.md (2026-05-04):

# SyncSpark Project Documentation

Welcome to the SyncSpark ESP32-CAM robot project documentation!

## Documentation Structure

- **Getting Started**: Hardware and software setup guides
- **Hardware**: Component specifications and wiring
- **Software**: Architecture and component documentation  
- **Troubleshooting**: Common issues and solutions

## Quick Links

- [WiFi Stack Overflow Solution](../WIFI_STACK_OVERFLOW_SOLUTION.md)
- [Configuration Template](../sdkconfig.defaults)
- [Main Application](../main/sparknode_i2c_test.c)

---
*SyncSpark ESP32-CAM Robot Project*

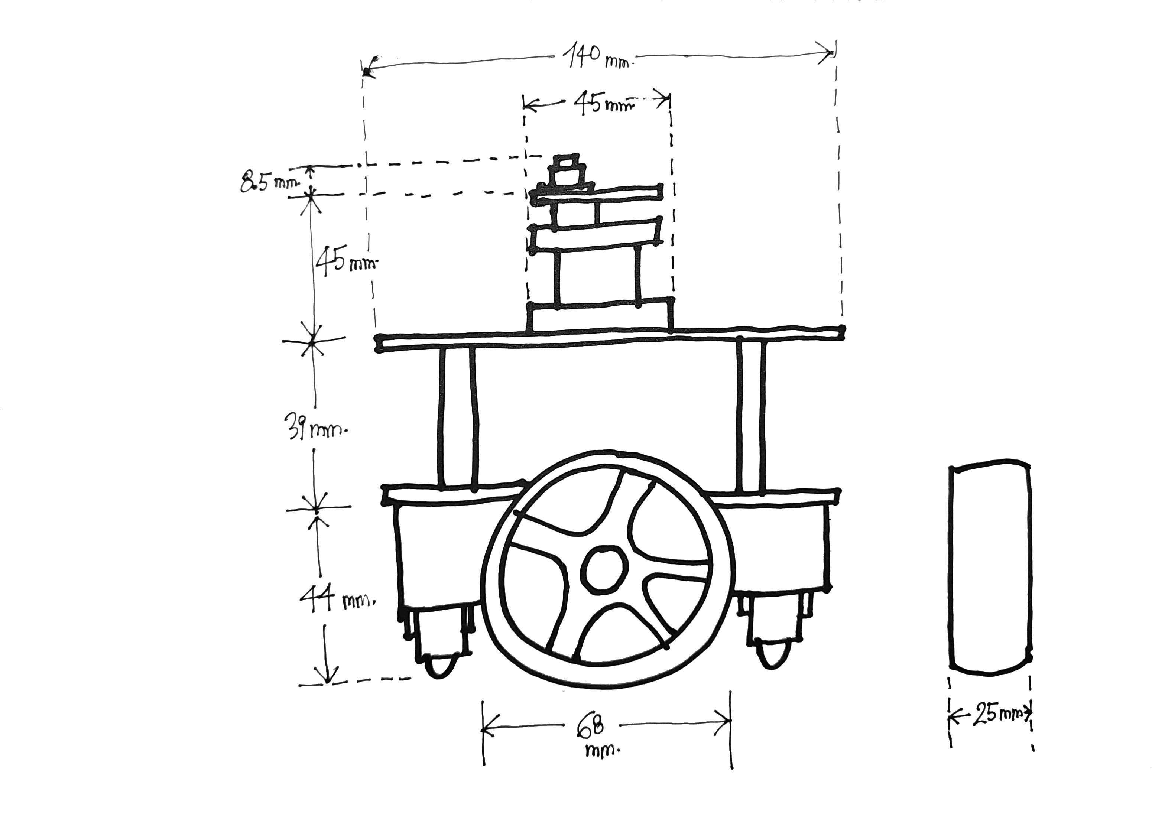
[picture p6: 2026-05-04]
docs/images/diagrams/spl_sparknode_measurements.jpg

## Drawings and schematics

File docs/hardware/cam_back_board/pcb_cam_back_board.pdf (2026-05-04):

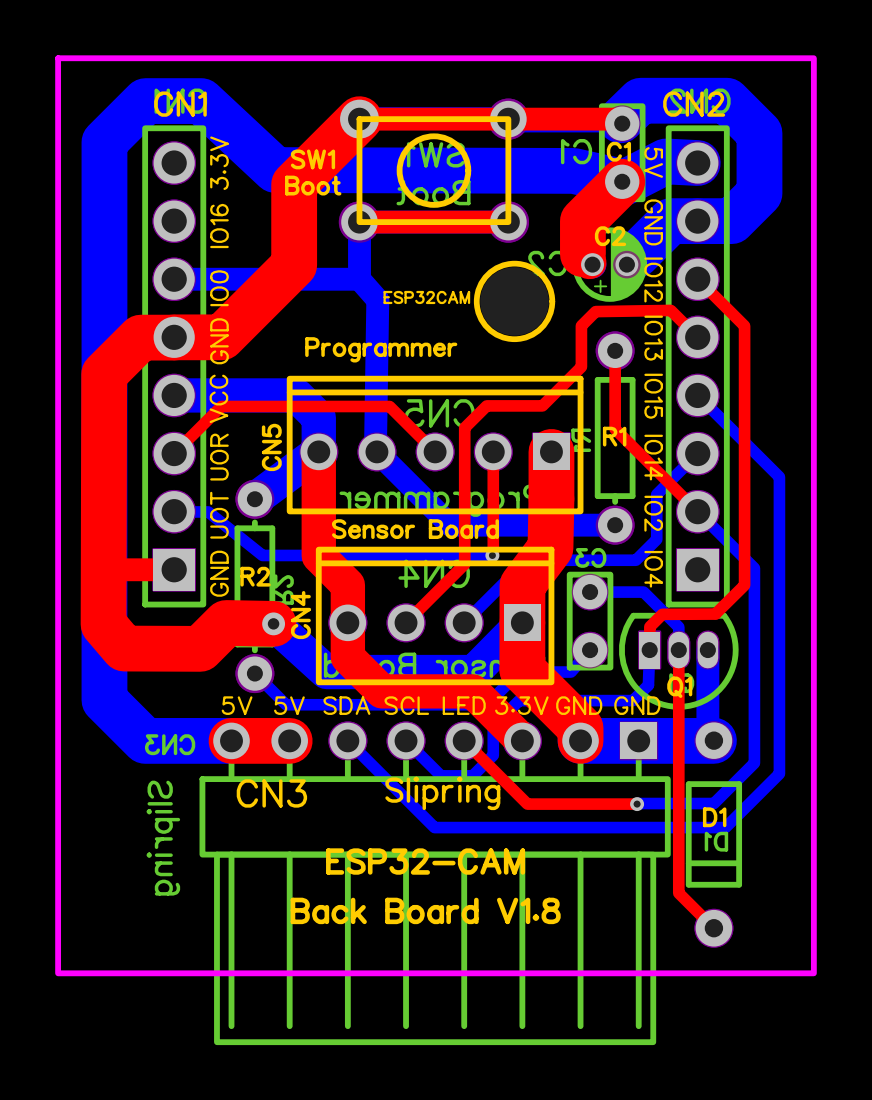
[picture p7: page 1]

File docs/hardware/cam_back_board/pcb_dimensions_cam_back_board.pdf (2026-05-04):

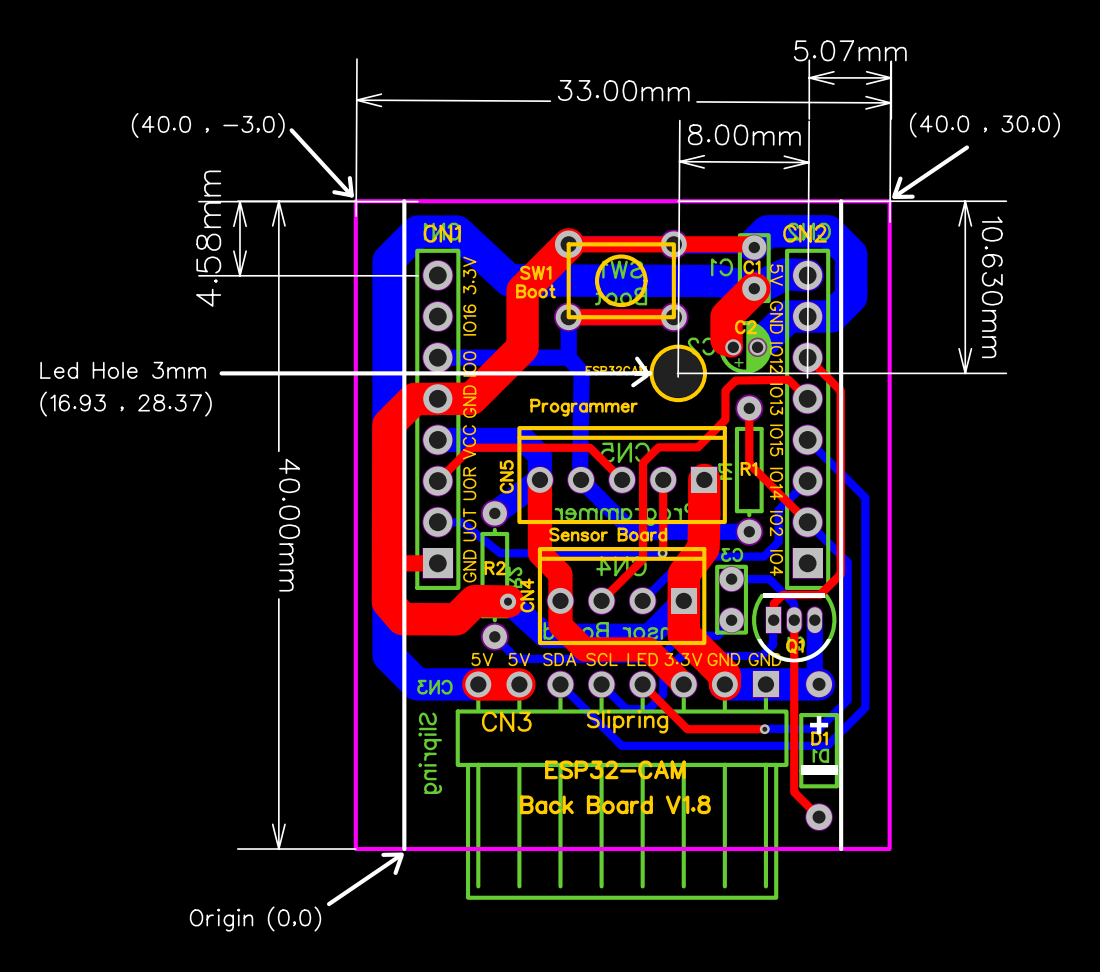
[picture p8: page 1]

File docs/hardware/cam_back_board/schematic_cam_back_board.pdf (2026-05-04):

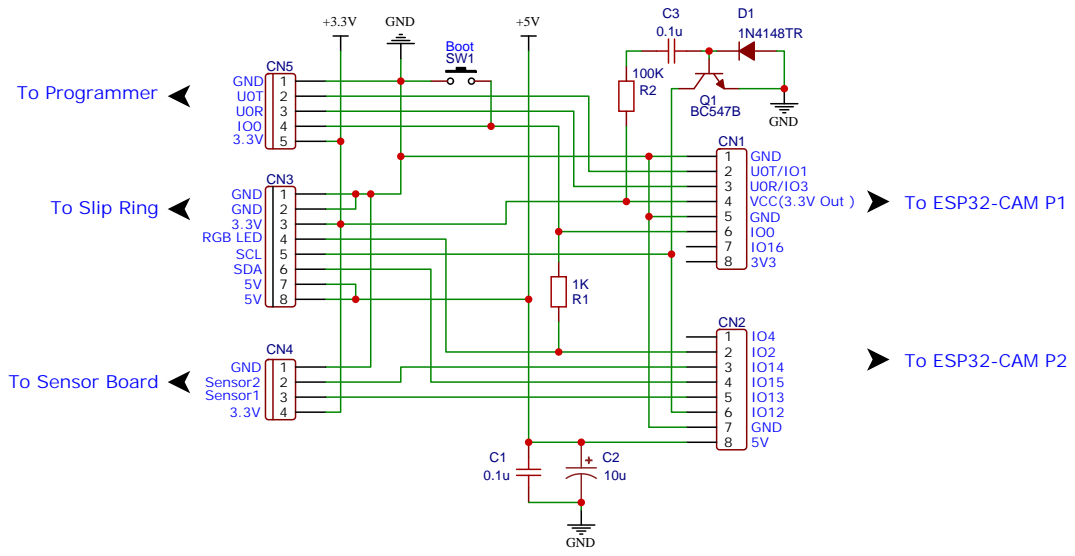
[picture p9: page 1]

Drawn By: ismet.atalar

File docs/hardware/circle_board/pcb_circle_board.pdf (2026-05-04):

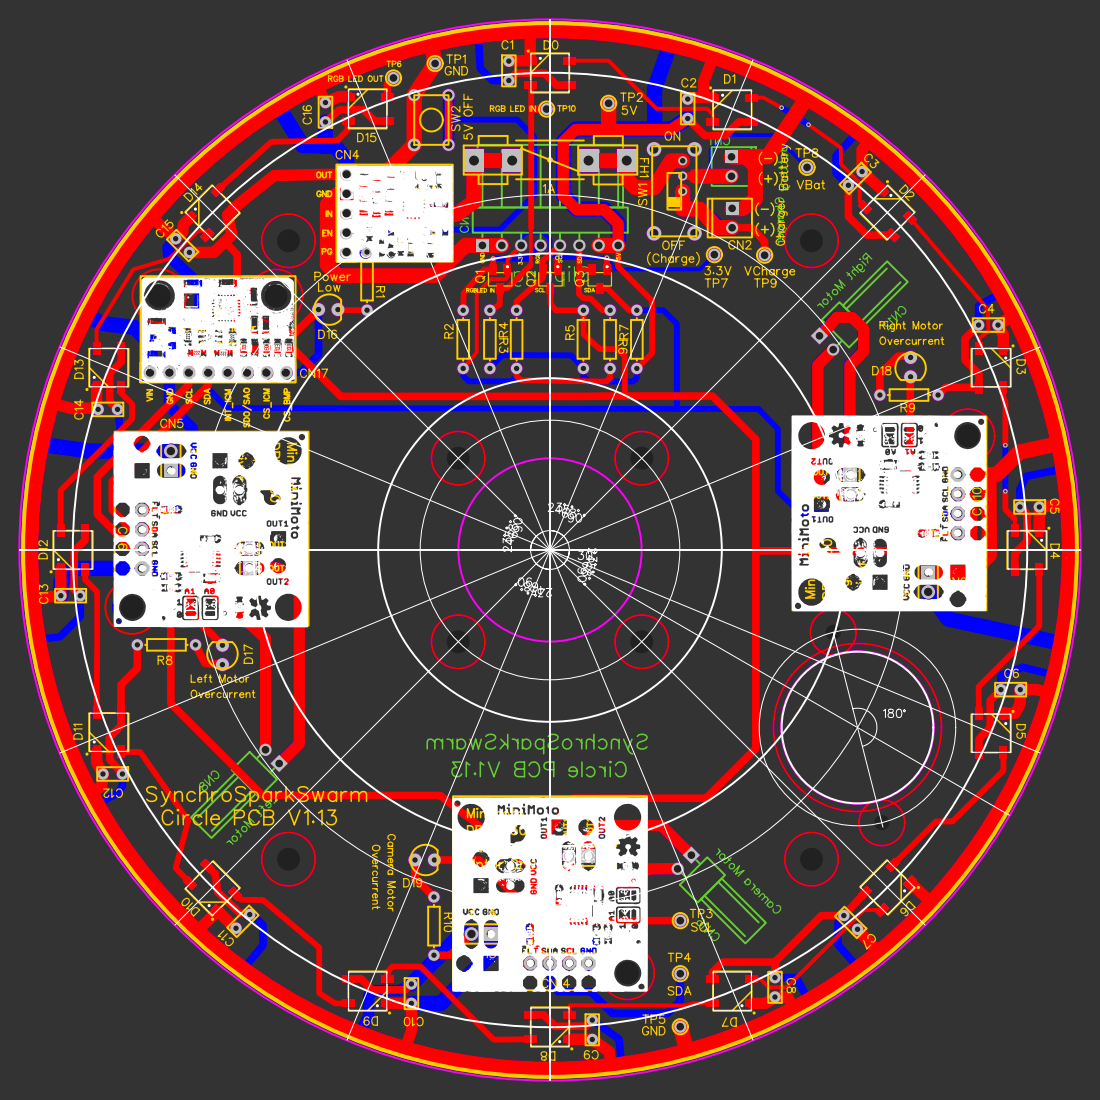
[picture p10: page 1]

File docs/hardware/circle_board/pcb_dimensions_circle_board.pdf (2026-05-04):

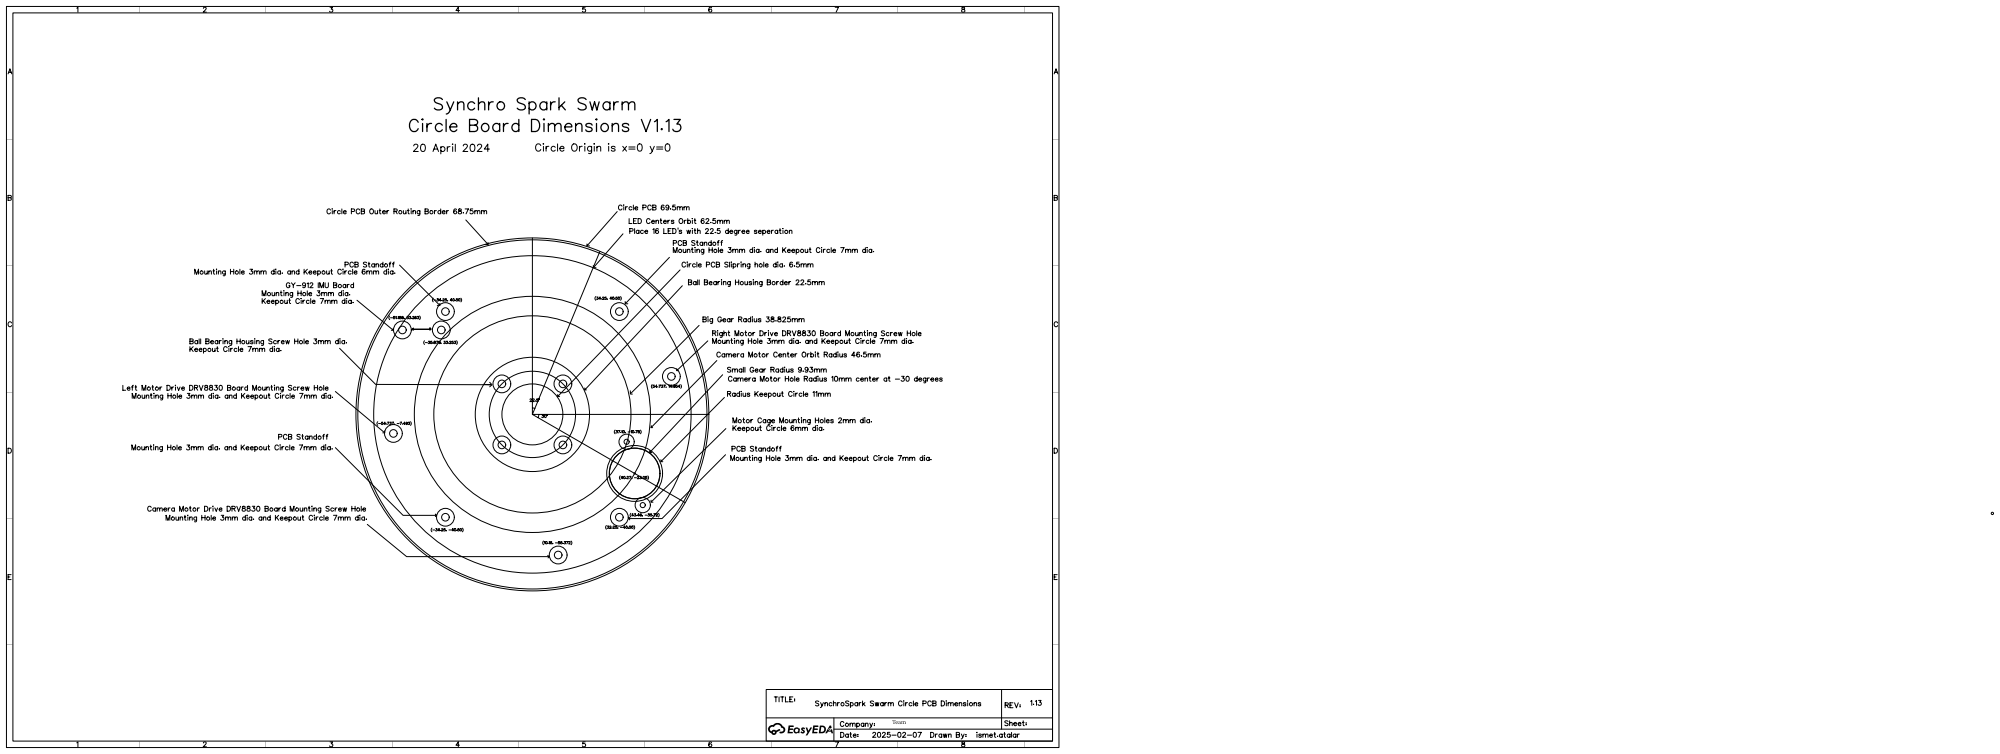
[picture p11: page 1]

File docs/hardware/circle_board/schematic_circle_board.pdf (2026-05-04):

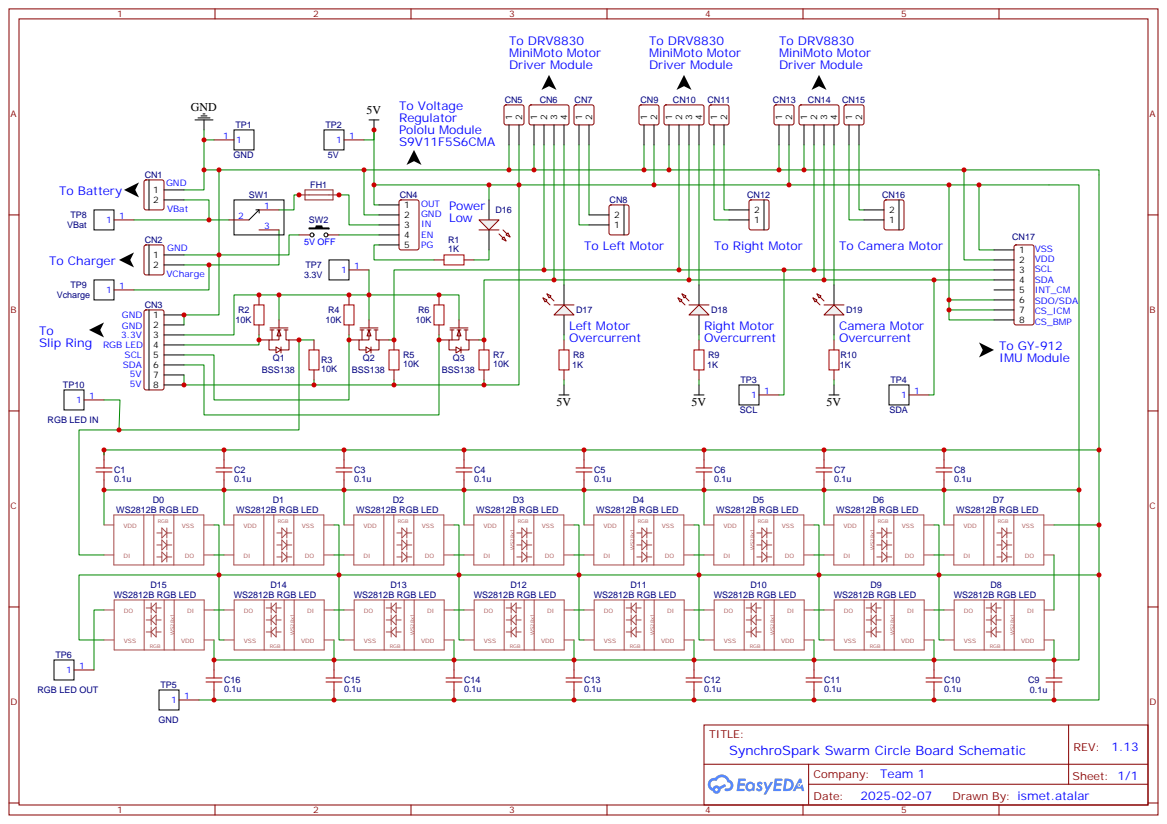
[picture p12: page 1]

Drawn By: ismet.atalar

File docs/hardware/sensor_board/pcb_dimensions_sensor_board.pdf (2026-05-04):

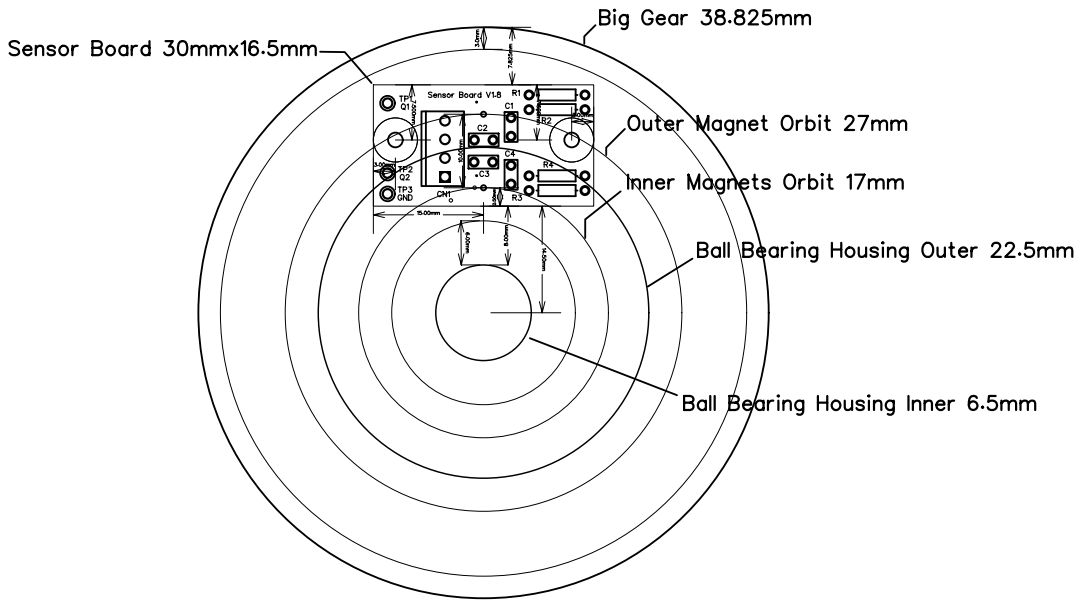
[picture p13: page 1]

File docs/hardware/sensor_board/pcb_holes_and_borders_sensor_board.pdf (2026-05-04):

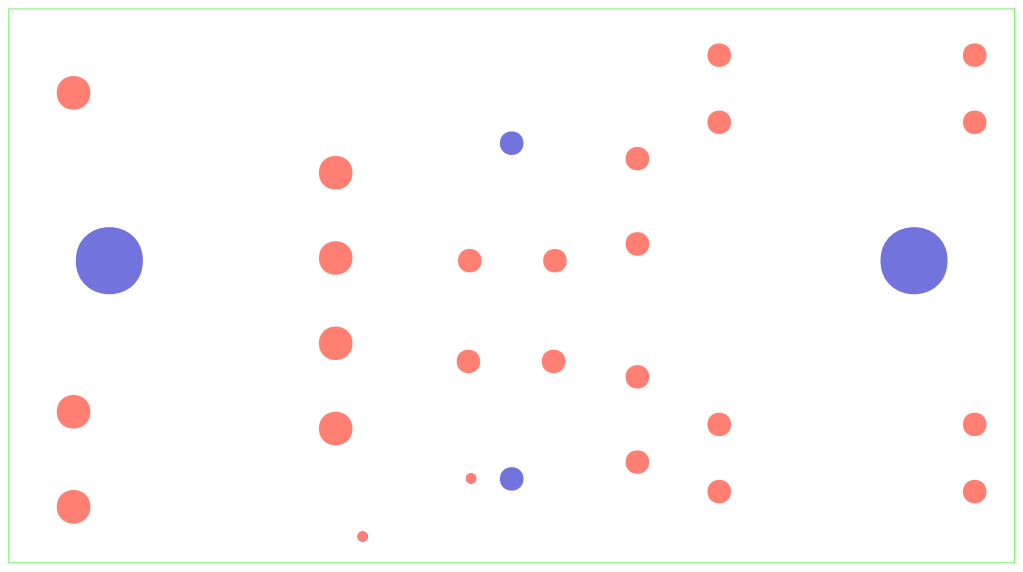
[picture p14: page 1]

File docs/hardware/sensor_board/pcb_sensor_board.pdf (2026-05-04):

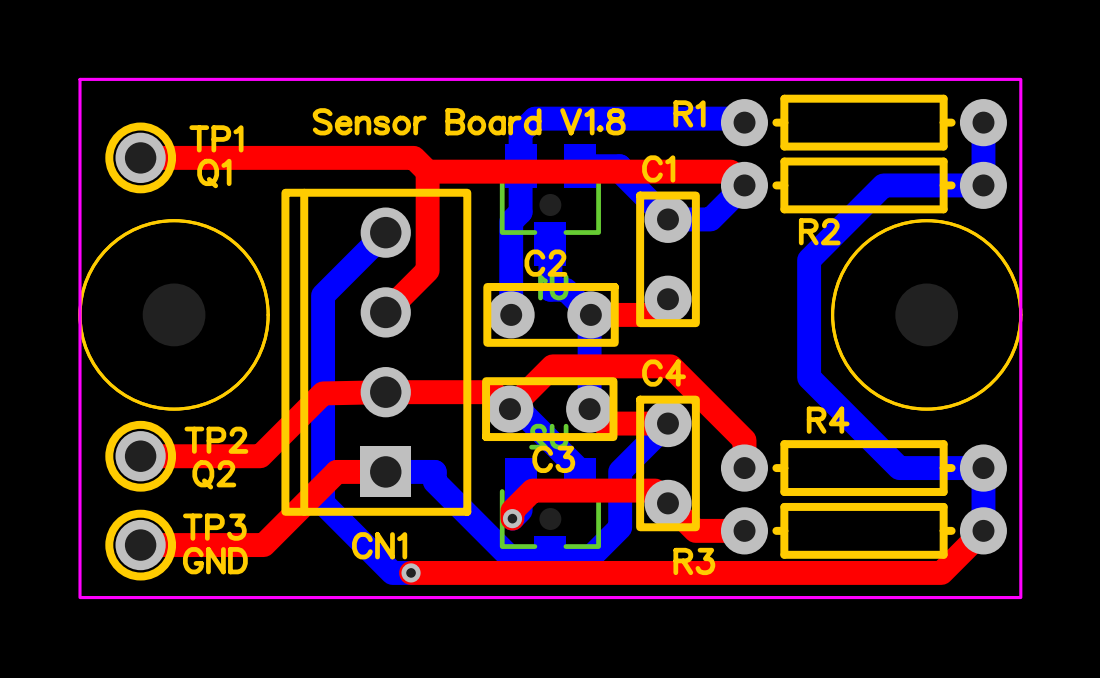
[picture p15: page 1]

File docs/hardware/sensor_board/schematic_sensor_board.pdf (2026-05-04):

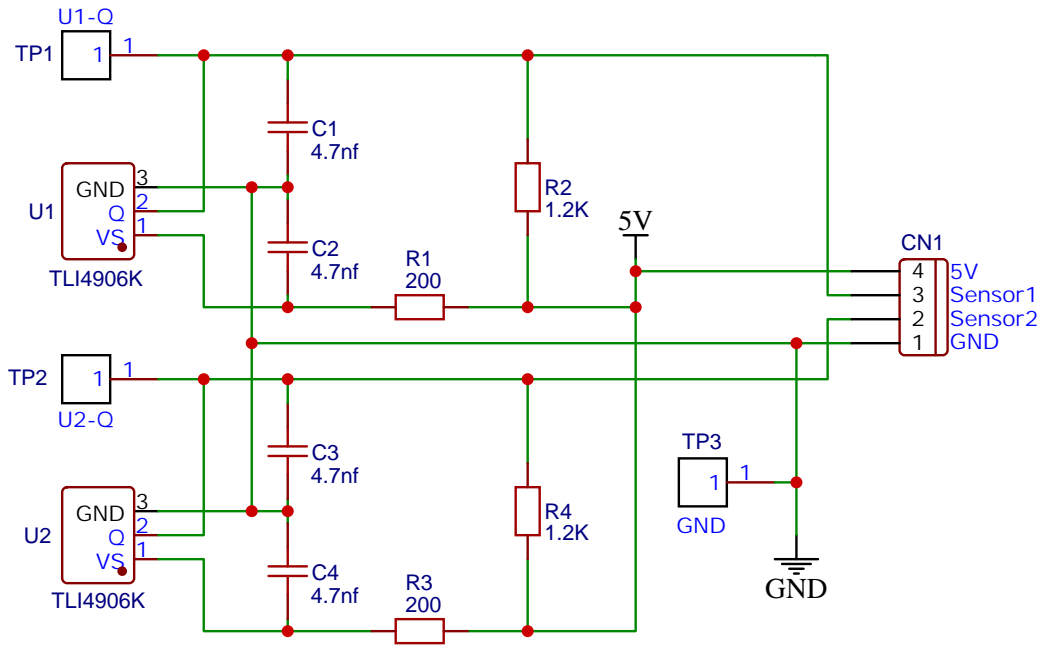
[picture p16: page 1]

Drawn By: ismet.atalar

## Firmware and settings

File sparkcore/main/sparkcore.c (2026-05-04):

/* SPDX-License-Identifier: GPL-3.0-or-later */

/*
 * sparkcore.c - Main SynchroSpark core application
 * 
 * Copyright (C) 2025-2026 Ahmet Sekercioglu and Ismet Atalar
 *
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
 * You should have received a copy of the GNU General Public License
 * along with this program. If not, see <https://www.gnu.org/licenses/>.
 */
 
/*
 * Important:
 * Do not flash this program to the device, it will be downloaded wirelessly by the OTA updater.
 * This program assumes that sparknode_ota_updater is already placed in the factory partition of
 * the device.
 */

#define OTA_UPDATE_ENABLED

#include "bmp388.h"
#include "drv5033.h"
#include "drv8830.h"
#include "fusion_interface.h"
#include "esp32_chip_info.h"
#include "esp_netif.h"
#include "esp_timer.h"
#include "freertos/FreeRTOS.h"
#include "icm20948.h"
#include "mqtt_handler.h"
#include "network_config.h"
#include "ota_utils.h"
#include "rgb_led_ring.h"
#include "syncspark_config.h"
#include "sys_utils.h"
#include "wifi_credentials.h"
#include "wifi_net.h"
#include <nvs_utils.h>
#include <stdio.h>

/*
Attention:

In our standard design, the RGB LED ring connects to GPIO 2 of the ESP32-CAM board. However,
GPIO 2 is one of the ESP32-CAM's strapping pins, meaning that if it is pulled high during boot,
the ESP32-CAM will not enter flashing mode. To address this issue, Ismet has designed a small
circuit on the camera back board that ensures GPIO 2 remains low during startup.

After flashing "sparknode_ota_updater" to the device via USB cable connection, we can safely
continue using GPIO 2 to control the RGB LED ring since subsequent firmware updates use the OTA
method. If USB flashing is needed again, either the back board circuit must be present to
hold GPIO 2 low during boot, or the RGB LED ring must be unplugged from GPIO 2 before flashing
the device.
*/

// Extern declarations for global sensor data (defined in syncspark_config.c)
// Inertial Measurement Unit (IMU) data structures and globals
extern icm20948_data_t g_sensor_data;  // Current gyro + accel data
extern icm20948_mag_data_t g_mag_data; // Current magnetometer data
extern volatile sensor_loop_mode_t g_sensor_loop_mode;
extern volatile uint32_t g_sensor_loop_iterations;
extern volatile uint32_t g_sensor_loop_delay_ms;
extern volatile bool g_sensor_stream_enabled;
extern volatile uint32_t g_sensor_stream_period_ms;
extern volatile sensor_stream_mode_t g_sensor_stream_mode;

static const char *TAG = "sparkcore";

static const float FUSION_GAIN_DEFAULT = 0.5f;
static const float FUSION_GAIN_ACCEL_GYRO = 3.0f;
static const float FUSION_GAIN_MAG_ACCEL = 3.0f;
static const float FUSION_GAIN_MAG_ACCEL_GYRO = 1.5f;

void initialize_i2c_master(i2c_master_bus_handle_t *p_i2c_bus_handle)
{
  i2c_master_bus_config_t i2c_mst_config = {
      .clk_source = I2C_CLK_SRC_DEFAULT,
      .i2c_port = I2C_NUM_0,
      .scl_io_num = I2C_MASTER_SCL_IO,
      .sda_io_num = I2C_MASTER_SDA_IO,
      .glitch_ignore_cnt = 7,
      .flags.enable_internal_pullup = true,
  };

  ESP_ERROR_CHECK(i2c_new_master_bus(&i2c_mst_config, p_i2c_bus_handle));
  ESP_LOGI("I2C", "I2C master initialization is successful.");
} // initialize_i2c_master()

void i2c_scan(i2c_master_bus_handle_t i2c_bus_handle)
{
  int i;
  int devices_found = 0;
  esp_err_t espRc;

  ESP_LOGI(TAG, "Starting I2C scan...");
  for (i = 1; i < 127; i++) {
    espRc = i2c_master_probe(i2c_bus_handle, i, -1);
    if (espRc == ESP_OK) {
      ESP_LOGI(TAG, "Found device at 0x%02x.", i);
      devices_found++;
    }
  }

  if (devices_found == 0) {
    ESP_LOGW(TAG, "No I2C devices detected!");
  } else {
    ESP_LOGI(TAG, "I2C scan complete, %d device(s) found.\n", devices_found);
  }

} // i2c_scan()

void task_blink_esp32cam_red_led(void *pvParameter)
{
  while (1) { // Blink the red LED continuously
    blink_esp32cam_red_led(200, 1000);
  }
} // task_blink_esp32cam_red_led()

void task_udp_heartbeat(void *pvParameter)
{
  static uint32_t i = 1;
  while (1) {
    blink_esp32cam_flash_led(9, 100);
    blink_esp32cam_flash_led(9, 100);

    // Get WiFi RSSI
    int rssi = -999;
    wifi_ap_record_t ap_info;
    if (esp_wifi_sta_get_ap_info(&ap_info) == ESP_OK) {
      rssi = ap_info.rssi;
    }
    ESP_LOGI("task UDP heartbeat", "(id %d) #%" PRIu32 " RSSI=%d dBm", g_sparknode_id, i++, rssi);
    vTaskDelay(pdMS_TO_TICKS(30000)); // Every 30 seconds
  }
} // task_udp_heartbeat()

void task_debug_hall_sensors(void *pvParameter)
{
  char *TAG = "hall_debug";
  uint32_t last_left_count = 0;
  uint32_t last_right_count = 0;

  while (1) {
    // Get current sensor states and counts
    bool sensor_1_state, sensor_2_state;
    get_sensor_states(&sensor_1_state, &sensor_2_state);
    uint32_t left_count = get_sensor_count(SENSOR_1);  // Left wheel
    uint32_t right_count = get_sensor_count(SENSOR_2); // Right wheel

    // Log when individual wheel counts change
    if (left_count != last_left_count) {
      float revolutions = calculate_wheel_revolutions(SENSOR_1);
      float angle = calculate_wheel_angle_degrees(SENSOR_1);
      ESP_LOGI(TAG, "L. wheel count - %lu -> %lu (+%lu) | Revs: %.3f | Angle: %.1f°", (unsigned long)last_left_count,
               (unsigned long)left_count, (unsigned long)(left_count - last_left_count), revolutions, angle);
      last_left_count = left_count;
    }

    if (right_count != last_right_count) {
      float revolutions = calculate_wheel_revolutions(SENSOR_2);
      float angle = calculate_wheel_angle_degrees(SENSOR_2);
      ESP_LOGI(TAG, "R. wheel count - %lu -> %lu (+%lu) | Revs: %.3f | Angle: %.1f°", (unsigned long)last_right_count,
               (unsigned long)right_count, (unsigned long)(right_count - last_right_count), revolutions, angle);
      last_right_count = right_count;
    }

    // Check if wheels are moving and calculate RPM for each
    bool left_moving = is_wheel_moving(SENSOR_1, 1000);
    bool right_moving = is_wheel_moving(SENSOR_2, 1000);

    if (left_moving) {
      float rpm = calculate_wheel_rpm(SENSOR_1, 2000);
      if (rpm > 0) {
        // ESP_LOGI(TAG, "Left wheel moving - RPM = %.1f", rpm);
      }
    }

    if (right_moving) {
      float rpm = calculate_wheel_rpm(SENSOR_2, 2000);
      if (rpm > 0) {
        // ESP_LOGI(TAG, "Right wheel moving - RPM = %.1f", rpm);
      }
    }

    vTaskDelay(pdMS_TO_TICKS(250)); // Check periodically
  }
} // task_debug_hall_sensors()

// Structure to pass parameters to sensor fusion task
typedef struct {
  i2c_master_dev_handle_t icm20948_dev_handle;
  mag_calibration_t mag_bias;
  icm20948_data_t gyro_bias;
} sensor_fusion_params_t;

void task_sensor_fusion(void *pvParameter)
{
  sensor_fusion_params_t *params = (sensor_fusion_params_t *)pvParameter;
  char *TAG = "task_sensor_fusion";
  static int sample_count = 1;

  ESP_LOGI(TAG, "Sensor fusion task started");

  // Timing state for adaptive dt
  static uint64_t last_us = 0;
  static uint64_t last_stream_us = 0;
  static int accel_gyro_seed_pending = 0;
  static int accel_gyro_seed_samples = 0;
  static float accel_gyro_seed_sum_sin = 0.0f;
  static float accel_gyro_seed_sum_cos = 0.0f;
  static float accel_gyro_seed_heading = 0.0f;
  const int accel_gyro_seed_target = 5;

  while (1) {
    if (g_sensor_loop_mode == SENSOR_LOOP_STOP) {
      vTaskDelay(pdMS_TO_TICKS(100)); // idle
      continue;
    }
    if (g_sensor_loop_mode == SENSOR_LOOP_COUNTED && g_sensor_loop_iterations == 0) {
      g_sensor_loop_mode = SENSOR_LOOP_STOP;
      vTaskDelay(pdMS_TO_TICKS(100));
      continue;
    }

    // Read sensors into global structures
    // Read calibrated gyro + accel
    icm20948_data_t calibrated_gyro_accel;
    esp_err_t gyro_ret =
        icm20948_read_gyro_calibrated(params->icm20948_dev_handle, &params->gyro_bias, &calibrated_gyro_accel);
    if (gyro_ret == ESP_OK) {
      g_sensor_data = calibrated_gyro_accel;
    } else {
      static uint32_t gyro_err_count = 0;
      gyro_err_count++;
      if (gyro_err_count <= 3 || (gyro_err_count % 50) == 0) {
        ESP_LOGW(TAG, "Gyro/accel read failed (total=%u): %s", (unsigned)gyro_err_count, esp_err_to_name(gyro_ret));
      }
    }

    // Read calibrated magnetometer (no retries; log source only).
    icm20948_mag_data_t calibrated_mag;
    esp_err_t mag_ret = icm20948_read_mag_calibrated(params->icm20948_dev_handle, &g_mag_bias, &calibrated_mag);
    if (mag_ret == ESP_OK) {
      g_mag_data = calibrated_mag;
    } else {
      static uint32_t mag_err_count = 0;
      mag_err_count++;
      if (mag_err_count <= 3 || (mag_err_count % 50) == 0) {
        ESP_LOGW(TAG, "Mag read failed (total=%u): %s", (unsigned)mag_err_count, esp_err_to_name(mag_ret));
      }
    }

    // Remap sensor axes into the robot frame for the current ICM20948
    // mounting: accel/gyro +X is forward, gyro +X is right-roll positive,
    // gyro +Y is nose-down, gyro +Z is CCW, mag +X is north/forward,
    // mag +Y is east/right, and mag +Z points down.
    float gx = g_sensor_data.gyro_x;
    float gy = -g_sensor_data.gyro_y;
    float gz = -g_sensor_data.gyro_z;

    float accx = -g_sensor_data.accel_x;
    float accy = g_sensor_data.accel_y;
    float accz = g_sensor_data.accel_z;

    float mx_cal = -g_mag_data.mag_y;
    float my_cal = g_mag_data.mag_x;
    float mz_cal = -g_mag_data.mag_z;

    // Magnetometer heading (diagnostic).
    float heading;
    heading = atan2f(mx_cal, my_cal) * (180.0f / M_PI);
    if (heading < 0)
      heading += 360.0f;
    ESP_LOGI("task sensor_fusion loop", "Magnetometer heading = %.2f deg", heading);

    static sensor_stream_mode_t prev_mode = MODE_MAG_ACCEL_GYRO;
    if (g_sensor_stream_mode != prev_mode) {
      if (g_sensor_stream_mode == MODE_ACCEL_GYRO) {
        fusion_set_gain(FUSION_GAIN_ACCEL_GYRO);
        fusion_reset();
        accel_gyro_seed_pending = 1;
        accel_gyro_seed_samples = 0;
        accel_gyro_seed_sum_sin = 0.0f;
        accel_gyro_seed_sum_cos = 0.0f;
        accel_gyro_seed_heading = heading;
      } else if (g_sensor_stream_mode == MODE_MAG_ACCEL) {
        fusion_set_gain(FUSION_GAIN_MAG_ACCEL);
        fusion_reset();
        accel_gyro_seed_pending = 0;
      } else if (g_sensor_stream_mode == MODE_MAG_ACCEL_GYRO) {
        fusion_set_gain(FUSION_GAIN_MAG_ACCEL_GYRO);
        fusion_reset();
        accel_gyro_seed_pending = 0;
      } else {
        fusion_set_gain(FUSION_GAIN_DEFAULT);
        accel_gyro_seed_pending = 0;
      }
      prev_mode = g_sensor_stream_mode;
    }

    // Adaptive dt calculation
    uint64_t now_us = esp_timer_get_time();
    float dt = (last_us == 0) ? (g_sensor_loop_delay_ms / 1000.0f) : (now_us - last_us) / 1e6f;
    last_us = now_us;

    // Convert dt to ms for logging (kept as comment to avoid unused var)
    // float dt_ms = dt * 1000.0f;

    // Update the selected fusion backend.
    if (g_sensor_stream_mode == MODE_ACCEL_GYRO) {
      if (accel_gyro_seed_pending && mag_ret == ESP_OK) {
        const float heading_rad = heading * ((float)M_PI / 180.0f);
        accel_gyro_seed_sum_sin += sinf(heading_rad);
        accel_gyro_seed_sum_cos += cosf(heading_rad);
        accel_gyro_seed_samples++;
        accel_gyro_seed_heading = atan2f(accel_gyro_seed_sum_sin, accel_gyro_seed_sum_cos) * (180.0f / (float)M_PI);
        if (accel_gyro_seed_heading < 0.0f) {
          accel_gyro_seed_heading += 360.0f;
        }

        if (accel_gyro_seed_samples >= accel_gyro_seed_target) {
          fusion_seed_imu_yaw(accel_gyro_seed_heading, accx, accy, accz);
          accel_gyro_seed_pending = 0;
        }
      }

      if (!accel_gyro_seed_pending) {
        fusion_update_imu(gx, gy, gz, accx, accy, accz, dt);
      }
    } else if (g_sensor_stream_mode == MODE_MAG_ACCEL) {
      fusion_update(0.0f, 0.0f, 0.0f, accx, accy, accz, mx_cal, my_cal, mz_cal, dt);
    } else if (g_sensor_stream_mode == MODE_MAG_ACCEL_GYRO) {
      fusion_update(gx, gy, gz, accx, accy, accz, mx_cal, my_cal, mz_cal, dt);
    }

    static float yaw_integrated_rad = 0.0f;

    if (dt > 0.0f) {
      yaw_integrated_rad += gz * dt;
    }
    float yaw_integrated_deg = fmodf(yaw_integrated_rad * (180.0f / M_PI), 360.0f);
    if (yaw_integrated_deg < 0)
      yaw_integrated_deg += 360.0f;

    // Get orientation
    float yaw, pitch, roll;
    if (g_sensor_stream_mode == MODE_MAG) {
      yaw = heading;
      pitch = 0.0f;
      roll = 0.0f;
    } else if (g_sensor_stream_mode == MODE_ACCEL_GYRO && accel_gyro_seed_pending) {
      yaw = accel_gyro_seed_heading;
      pitch = -atan2f(accx, sqrtf(accy * accy + accz * accz)) * (180.0f / (float)M_PI);
      roll = atan2f(accy, accz) * (180.0f / (float)M_PI);
    } else {
      fusion_get_orientation(&yaw, &pitch, &roll);
    }

    ESP_LOGI(TAG, "Euler: Yaw=%.2f deg. Pitch=%.2f deg. Roll=%.2f deg.", yaw, pitch, roll);

    if (g_sensor_stream_enabled && g_mqtt_client) {
      uint64_t now_us_stream = esp_timer_get_time();
      uint64_t period_us = (uint64_t)g_sensor_stream_period_ms * 1000ULL;
      if (period_us == 0) {
        period_us = 1000ULL;
      }
      if ((now_us_stream - last_stream_us) >= period_us) {
        char topic[64];
        char payload[160];
        snprintf(topic, sizeof(topic), "arena/%s/orientation", g_hostname);
        snprintf(payload, sizeof(payload), "{\"yaw\":%.2f,\"pitch\":%.2f,\"roll\":%.2f}", yaw, pitch, roll);
        esp_mqtt_client_publish(g_mqtt_client, topic, payload, 0, 0, 0);
        last_stream_us = now_us_stream;
      }
    }

    // Log all three together
    // ESP_LOGI(TAG, "sample= %d", sample_count);
    // ESP_LOGI(TAG, "dt= %.2f ms", dt_ms);
    // ESP_LOGI(TAG, "g_x = %.2f, g_y = %.2f, g_z = %.2f, a_x = %.2f, a_y = %.2f, a_z = %.2f",
    //                      gx, gy, gz, accx, accy, accz);
    // ESP_LOGI(TAG, "RawMagYaw= %.2f deg, GyroIntYaw= %.2f deg, FusedYaw= %.2f deg, (Pitch= %.2f deg, Roll= %.2f
    // deg)\n\n",
    //               heading, yaw_integrated_deg, yaw, pitch, roll);

    sample_count++;

    // Handle counted mode
    if (g_sensor_loop_mode == SENSOR_LOOP_COUNTED) {
      if (g_sensor_loop_iterations > 0) {
        g_sensor_loop_iterations--;
      }
      if (g_sensor_loop_iterations == 0) {
        g_sensor_loop_mode = SENSOR_LOOP_STOP;
      }
    }
    vTaskDelay(pdMS_TO_TICKS(g_sensor_loop_delay_ms));
  }
} // task_sensor_fusion()

void app_main(void)
{
  /*
    Outline of app_main():
    1. Basic setup (LEDs, NVS, MAC, hostname)
    2. WiFi initialization
    3. UDP logging setup
    4. RGB LED ring setup
    5. Hall sensor initialization
    6. I2C device handles initialization
    7. MQTT client start
    8. IMU sensors setup and calibration
    9. Task creation
  */
  char *TAG = "sparkcore main";
  int rgb_led_ring_gpio_pin = RGB_LED_RING_GPIO_PIN;
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

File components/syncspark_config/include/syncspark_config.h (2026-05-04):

/* SPDX-License-Identifier: GPL-3.0-or-later */

/*
 * syncspark_config.h - Configuration for SynchroSpark nodes
 * 
 * Copyright (C) 2025-2026 Ahmet Sekercioglu and Ismet Atalar
 *
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
 * You should have received a copy of the GNU General Public License
 * along with this program. If not, see <https://www.gnu.org/licenses/>.
 */

// Configuration file for a SynchroSpark Node
#ifndef SYNCSPARK_CONFIG_H
#define SYNCSPARK_CONFIG_H

#include "driver/i2c_master.h"
#include "led_strip.h"
#include <stdint.h>
#include <stdbool.h>

// Forward declaration to avoid pulling mqtt headers into all components.
struct esp_mqtt_client;
typedef struct esp_mqtt_client *esp_mqtt_client_handle_t;

// I2C communications
/*
  I2C addresses, our settings:
    0x61 camera motor controller
    0x63 left wheel motor controller
    0x64 right wheel motor controller
    0x69 gy-912
    0x76 gy-912 BMP388
*/

#define I2C_MASTER_SCL_IO           GPIO_NUM_12  // GPIO number for I2C master clock
#define I2C_MASTER_SDA_IO           GPIO_NUM_15  // GPIO number for I2C master data
#define I2C_MASTER_NUM              I2C_NUM_0    // I2C port number for master dev
#define I2C_MASTER_FREQ1_HZ         400000       // I2C master clock frequency
#define I2C_MASTER_FREQ2_HZ         100000       // I2C master clock frequency
#define I2C_MASTER_TIMEOUT_MS       1000	     // Timeout for I2C operations

#define CAM_MOTOR_I2C_ADDR          ((uint16_t) 0x61)
#define LEFT_MOTOR_I2C_ADDR         ((uint16_t) 0x63)
#define RIGHT_MOTOR_I2C_ADDR        ((uint16_t) 0x64)           
#define ICM20948_I2C_ADDR           ((uint16_t) 0x68) //0x69 AD0 High, 0x68 AD0 Low
#define BMP388_I2C_ADDR             ((uint16_t) 0x76) //0x77 AD0 High, 0x76 AD0 Low

// Wheel sensor GPIOs
// Assumptions (adjust if wiring differs):
//  - GPIO13 -> left wheel sensor passing over magnets
//  - GPIO14 -> right wheel sensor passing over magnets
// If reversed, swap the macros below in one place.
#define LEFT_WHEEL_SENSOR   GPIO_NUM_13
#define RIGHT_WHEEL_SENSOR  GPIO_NUM_14

// Circle board's RGB LED strip 
#define RGB_LED_RING_GPIO_PIN  GPIO_NUM_2
#define RGB_LED_RING_LED_COUNT 16 

typedef struct {
    uint8_t mac[6];
    uint8_t id;
} mac_id_map_t;

extern const mac_id_map_t g_mac_id_table[];
extern const size_t g_mac_id_table_size;
//extern const uint8_t g_debruijn_sequences[15][16];
extern const uint8_t g_debruijn_sequences[123][16];

// Per-sparknode motor configuration parameters
typedef struct {
    // Motor calibration parameters
    float left_motor_speed_multiplier;   // Adjust for motor differences (default: 1.0)
    float right_motor_speed_multiplier;  // Adjust for motor differences (default: 1.0)
    
    // Kick-start parameters for static friction
    uint8_t kick_speed;                  // Initial high speed to overcome static friction (default: 0x3F)
    uint16_t kick_duration_ms;           // How long to apply kick speed (default: 100ms)
    
    // Default motion parameters
    uint8_t default_drive_speed;         // Default speed for drive commands (default: 0x20)
    uint8_t default_turn_speed;          // Default speed for turn commands (default: 0x20)
    uint32_t default_drive_duration_ms;  // Default duration for drive commands (default: 2000ms)
    uint32_t default_turn_duration_ms;   // Default duration for turn commands (default: 1000ms)
    
    // Configuration status
    bool use_kick_start;                 // Whether to use kick-start mechanism
} sparknode_motor_config_t;

// Global variables
extern led_strip_handle_t g_rgb_led_ring_handle;
extern i2c_master_bus_handle_t g_i2c_bus_handle;
extern i2c_master_dev_handle_t g_cam_motor_dev_handle;
extern i2c_master_dev_handle_t g_left_motor_dev_handle;
extern i2c_master_dev_handle_t g_right_motor_dev_handle;
extern i2c_master_dev_handle_t g_bmp388_dev_handle;
extern i2c_master_dev_handle_t g_icm20948_dev_handle;
extern TaskHandle_t g_rgb_led_ring_task_handle;
extern esp_mqtt_client_handle_t g_mqtt_client;

// Global device identity variables
extern uint8_t g_sparknode_id;
extern char g_hostname[32];

// Global motor configuration instance
extern sparknode_motor_config_t g_motor_config;

// IMU sensor data structures
typedef enum {
    SENSOR_LOOP_STOP = 0,
    SENSOR_LOOP_INFINITE = 1,
    SENSOR_LOOP_COUNTED = 2
} sensor_loop_mode_t;

typedef enum {
    MODE_MAG_ACCEL_GYRO = 0,
    MODE_ACCEL_GYRO = 1,
    MODE_MAG = 2,
    MODE_MAG_ACCEL = 3
} sensor_stream_mode_t;

// IMU sensor loop control variables (defined in syncspark_config.c)
extern volatile sensor_loop_mode_t g_sensor_loop_mode;
extern volatile uint32_t g_sensor_loop_iterations;
extern volatile uint32_t g_sensor_loop_delay_ms;
extern volatile bool g_sensor_stream_enabled;
extern volatile uint32_t g_sensor_stream_period_ms;
extern volatile sensor_stream_mode_t g_sensor_stream_mode;

#endif

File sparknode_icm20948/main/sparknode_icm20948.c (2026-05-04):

/* SPDX-License-Identifier: GPL-3.0-or-later */

/*
 * sparknode_icm20948.c - IMU sensor node for SynchroSpark
 * 
 * Copyright (C) 2025-2026 Ahmet Sekercioglu and Ismet Atalar
 *
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
 * Important:
 * Do not flash this program to the device, it will be downloaded wirelessly by the OTA updater.
 * This program assumes that sparknode_ota_updater is already placed in the factory partition of
 * the device.
 */

#define OTA_UPDATE_ENABLED

/*
include <stdio.h>
#include <nvs_flash.h>
#include "freertos/FreeRTOS.h"
#include "esp32_chip_info.h"
#include "syncspark_config.h"
#include "sys_utils.h"
//#include "rgb_led_ring.h"  // Now includes set_leds_from_debruijn_sequence()
#include "ota_utils.h"
#include "wifi_net.h"
#include "wifi_credentials.h"
#include "network_config.h"

*/



#include <stdio.h>
#include <string.h>
#include "math.h"
#include "freertos/FreeRTOS.h"
#include "freertos/task.h"
#include "esp32_chip_info.h"
#include "syncspark_config.h"
#include "sys_utils.h"
#include "nvs_utils.h"

#include "nvs_flash.h"
#include "nvs.h"

//#include <nvs_flash.h>
//#include "rgb_led_ring.h"
#include "ota_utils.h"
#include "wifi_net.h"
#include "bmp388.h"
#include "icm20948.h"
#include "esp_pm.h"
#include "esp32_chip_info.h"
#include "esp_log.h"
#include "esp_sleep.h"
#include "driver/gpio.h"
#include <inttypes.h>
#include "esp_timer.h"
#include "madgwick_interface.h"
#include "MadgwickAHRS.h"

// Create your own file to define these macros:
// #define WIFI_SSID "your wifi ssid here"
// #define WIFI_PASS "your wifi password here"
#include "wifi_credentials.h"

// Contains definitions of DESTINATION_IP_ADDR, DESTINATION_UDP_PORT, 
// LOG_SERVER_IP_ADDR, LOG_SERVER_UDP_PORT, UDP_PACKET_SIZE,
// CHECKSUM_FILE_URL and BINARY_FILE_URL
#include "network_config.h" 

static const char *TAG = "main";
static uint8_t g_sparknode_id = 0; // Will be set after reading the MAC address

/*
void task_blink_esp32cam_red_led(void *pvParameter)
{
  while (1) {
    blink_esp32cam_red_led (200, 1200);	// Blink the red LED continuously
  }
} // task_blink_esp32cam_red_led()

void task_udp_heartbeat(void *pvParameter) {
  static uint32_t i = 1;
  while (1) {
    blink_esp32cam_flash_led(9, 100);
    blink_esp32cam_flash_led(9, 100);
    ESP_LOGI("UDP heartbeat", "(id %d) %" PRIu32, g_sparknode_id, i++);
    vTaskDelay(pdMS_TO_TICKS(10000)); // Every 10 seconds
    }
} // task_udp_heartbeat()
*/
i2c_master_bus_handle_t bus_handle;

void i2c_master_initialize() {
  i2c_master_bus_config_t i2c_mst_config = {
      .clk_source = I2C_CLK_SRC_DEFAULT,
      .i2c_port = I2C_NUM_0,
      .scl_io_num = I2C_MASTER_SCL_IO,
      .sda_io_num = I2C_MASTER_SDA_IO,
      .glitch_ignore_cnt = 7,
      .flags.enable_internal_pullup = true,
  };
  ESP_ERROR_CHECK(i2c_new_master_bus(&i2c_mst_config, &bus_handle));
  ESP_LOGI(TAG, "I2C Master initialized successfully");
}

void i2c_scan() {
  ESP_LOGI(TAG, "Starting I2C scan...");
  int devices_found = 0;
  for (int i = 1; i < 127; i++) {
      if (i2c_master_probe(bus_handle, i, -1) == ESP_OK) {
          ESP_LOGI(TAG, "Found device at 0x%02x", i);
          devices_found++;
      }
  }
  if (devices_found == 0) {
      ESP_LOGW(TAG, "No I2C devices detected!");
  } else {
      ESP_LOGI(TAG, "I2C scan complete. %d device(s) found.", devices_found);
  }
}



void app_main(void) 
{
  static const char *TAG = "sparknode_icm20948";

  // We call set_next_boot_to_factory() at the very beginning of app_main()
  // to ensure that the next boot will use the factory partition.
  #ifdef OTA_UPDATE_ENABLED
    ESP_LOGI(TAG, "OTA update enabled");
    set_next_boot_to_factory();
  #endif // OTA_UPDATE_ENABLED

  initialize_esp32cam_leds(); // Initialize GPIO pins for built-in LEDs
  test_esp32cam_leds();       // Blink the Flash and red LEDs
  if (ESP_OK != initialize_nvs()) {
        ESP_LOGE(TAG, "Failed to initialize NVS");
        indicate_error_esp32cam_red_led();  
        return;
  }
  initialize_wifi_sta(WIFI_SSID, WIFI_PASS);
  blink_esp32cam_flash_led(9, 0);
  initialize_udp_log(LOG_SERVER_IP_ADDR, LOG_SERVER_UDP_PORT);
  ESP_LOGI(TAG, "Redirecting/copying log messages over UDP...");
  redirect_log_to_udp();

  indicate_success_esp32cam_flash_led();
  int64_t *start_time = malloc(sizeof(int64_t)); // Allocate memory for start_time
  *start_time = esp_timer_get_time();            // For measuring elapsed time
  get_chip_info(); fflush(stdout);

  wifi_ap_record_t ap_info;
  if (esp_wifi_sta_get_ap_info(&ap_info) == ESP_OK) {
    ESP_LOGI(TAG, "Connected to %s", (char *) ap_info.ssid);
    ESP_LOGI(TAG, "RSSI: %d dBm", ap_info.rssi);
  } else {
    ESP_LOGW(TAG, "Failed to get AP info");
  }

  uint8_t mac[6];
  esp_efuse_mac_get_default(mac);
  g_sparknode_id = mac_to_id(mac);
  if (g_sparknode_id == 0x00) {
      ESP_LOGE(TAG, "MAC address is not registered, cannot determine my SparkNode ID");
  } else {
      ESP_LOGI(TAG, "SparkNode ID is %d", g_sparknode_id);
  }
  /*
  if (pdPASS != xTaskCreate(&task_udp_heartbeat, "task_udp_heartbeat", 2048, NULL, 5, NULL)) {
      ESP_LOGE(TAG, "Failed to create UDP heartbeat task");
  } 

  if (pdPASS != xTaskCreate (&task_blink_esp32cam_red_led, "task_esp32cam_blink_red_led", 2048, NULL, 5, NULL)) {
      ESP_LOGE("app_main", "Failed to create esp32cam_blink_red_led task");
  }
    */

  i2c_master_initialize();
  i2c_scan();

  // BMP388 setup
  i2c_device_config_t bmp388_dev_cfg = {
    .dev_addr_length = I2C_ADDR_BIT_LEN_7,
    .device_address = BMP388_I2C_ADDR,
    .scl_speed_hz = I2C_MASTER_FREQ1_HZ,
  };
  i2c_master_dev_handle_t bmp388_dev_handle;
  ESP_ERROR_CHECK(i2c_master_bus_add_device(bus_handle, &bmp388_dev_cfg, &bmp388_dev_handle));

  initialize_bmp388(bmp388_dev_handle, I2C_MASTER_TIMEOUT_MS);
  bmp388_read_data(bmp388_dev_handle,I2C_MASTER_TIMEOUT_MS );


  // ICM20948 setup
  i2c_device_config_t icm20948_dev_cfg = {
    .dev_addr_length = I2C_ADDR_BIT_LEN_7,
    .device_address = ICM20948_ADDRESS,
    .scl_speed_hz = I2C_MASTER_FREQ1_HZ,
  };
  ESP_LOGI(TAG, "icm20948_dev_cfg struct created ");
  i2c_master_dev_handle_t icm20948_dev_handle;
  ESP_ERROR_CHECK(i2c_master_bus_add_device(bus_handle, &icm20948_dev_cfg, &icm20948_dev_handle));
  
  ESP_LOGI(TAG, "Starting verification ");
  icm20948_verify_device(icm20948_dev_handle);
  ESP_LOGI(TAG, "The end of app_main program");
  icm20948_initialize(icm20948_dev_handle);

  ESP_LOGI(TAG, "Starting temporary magnetometer read loop...");

  // After initializing icm20948_dev_handle
  
  mag_calibration_t mag_bias;
  esp_err_t cal_status = load_mag_calibration_from_nvs(&mag_bias);
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

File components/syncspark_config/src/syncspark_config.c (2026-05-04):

/* SPDX-License-Identifier: GPL-3.0-or-later */

/*
 * syncspark_config.c - Configuration implementation for SynchroSpark nodes
 * 
 * Copyright (C) 2025-2026 Ahmet Sekercioglu and Ismet Atalar
 *
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
 * You should have received a copy of the GNU General Public License
 * along with this program. If not, see <https://www.gnu.org/licenses/>.
 */

#include <stdio.h>
#include <stdint.h>
#include <stdbool.h>
#include "syncspark_config.h"
#include "icm20948.h"  // For sensor data type definitions

led_strip_handle_t g_rgb_led_ring_handle = NULL;
i2c_master_bus_handle_t g_i2c_bus_handle = NULL;
i2c_master_dev_handle_t g_cam_motor_dev_handle = NULL;
i2c_master_dev_handle_t g_left_motor_dev_handle = NULL;
i2c_master_dev_handle_t g_right_motor_dev_handle = NULL;
i2c_master_dev_handle_t g_bmp388_dev_handle = NULL;
i2c_master_dev_handle_t g_icm20948_dev_handle = NULL;
TaskHandle_t g_rgb_led_ring_task_handle = NULL;
esp_mqtt_client_handle_t g_mqtt_client = NULL;

// Global device identity variables
uint8_t g_sparknode_id = 0;  // Will be set after reading the MAC address
char g_hostname[32];

// Inertial Measurement Unit (IMU) sensor global data structures and variables
icm20948_data_t g_sensor_data = {0};      // Current gyro + accel data
icm20948_mag_data_t g_mag_data = {0};     // Current magnetometer data
volatile sensor_loop_mode_t g_sensor_loop_mode = SENSOR_LOOP_STOP;
volatile uint32_t g_sensor_loop_iterations = 0;
volatile uint32_t g_sensor_loop_delay_ms = 50;
volatile bool g_sensor_stream_enabled = false;
volatile uint32_t g_sensor_stream_period_ms = 100;
volatile sensor_stream_mode_t g_sensor_stream_mode = MODE_MAG_ACCEL_GYRO;

// MAC To SparkNode ID mapping
// 0x00 is reserved for "not found" or "unknown" devices.
// 0xFF is reserved for broadcast messages.
const mac_id_map_t g_mac_id_table[] = {
    { {0xE4,0x65,0xB8,0x6F,0x46,0xE4}, 0x01 }, // Ahmet's SparkNode prototype
    { {0x3C,0x71,0xBF,0xE2,0xEF,0x30}, 0x02 }, // LED ring
    { {0xC0,0x49,0xEF,0xD2,0x0F,0xD0}, 0x03 }, // Ismet's ESP32-CAM board
    { {0x24,0x62,0xAB,0xD5,0xE4,0x94}, 0x04 }, // Ismet's ESP32-CAM board
    { {0xD4,0xE9,0xF4,0xA7,0x12,0xF0}, 0x05 }, // Ismet's ESP32-CAM board
    { {0xE4,0x65,0xB8,0x6F,0x44,0xD4}, 0x06 }, // Ahmet's SPL SparkNode
    { {0xE0,0x5A,0x1B,0xAB,0x47,0xC4}, 0x07 }, // Andy's SPL SparkNode
    { {0x80,0xF3,0xDA,0xAE,0x30,0xC0}, 0x08 }, // LED ring
    { {0x80,0xF3,0xDA,0xAD,0x55,0xA4}, 0x09 }, // Andy's ESP32-CAM board
    { {0x80,0xF3,0xDA,0xAD,0x64,0x90}, 0x0A }, // Ahmet's ESP32-CAM board
    { {0x6C,0xC8,0x40,0x34,0x5D,0xEC}, 0x0B }, // Optical Wireless Lab
    { {0x68,0x25,0xDD,0x2E,0x94,0x4C}, 0x0C }, // Optical Wireless Lab
    { {0x6C,0xC8,0x40,0x34,0x80,0x94}, 0x0D }, // Optical Wireless Lab
    { {0x6C,0xC8,0x40,0x34,0x03,0x04}, 0x0E }, // Optical Wireless Lab
    { {0x6C,0xC8,0x40,0x34,0x5F,0x38}, 0x0F }, // Optical Wireless Lab
    { {0x6C,0xC8,0x40,0x34,0x3E,0x14}, 0x10 }, // Optical Wireless Lab
    { {0x6C,0xC8,0x40,0x34,0x79,0x98}, 0x11 }, // LED ring 
    // Add more entries as needed
};

const size_t g_mac_id_table_size = sizeof(g_mac_id_table) / sizeof(g_mac_id_table[0]);

// Global motor configuration instance with default values (updated for better quality motors)
sparknode_motor_config_t g_motor_config = {
    .left_motor_speed_multiplier = 1.0f,
    .right_motor_speed_multiplier = 1.0f,
    .kick_speed = 0x2F,                    // Maximum kick speed (kept for manual override if needed)
    .kick_duration_ms = 50,                // kick duration in milliseconds
    .default_drive_speed = 0x20,           // Current working speed (32/63)
    .default_turn_speed = 0x20,            // Current working turn speed
    .default_drive_duration_ms = 2000,     // 2 second default drive
    .default_turn_duration_ms = 1000,      // 1 second default turn
    .use_kick_start = false                // Disabled by default for better quality motors
};

/*
// 16 LEDs, with three colors each, 
// 5 consecutive LEDs form a unique pattern
const uint8_t g_debruijn_sequences[15][16] = {
    { 2, 2, 1, 0, 0, 2, 0, 2, 1, 2, 2, 1, 2, 2, 0, 1 },
    { 0, 1, 0, 0, 0, 1, 0, 2, 1, 2, 0, 1, 2, 1, 0, 1 },
    { 2, 0, 1, 1, 1, 1, 0, 0, 0, 2, 2, 2, 2, 2, 1, 0 },
    { 0, 2, 0, 1, 0, 2, 2, 0, 2, 2, 2, 0, 1, 0, 1, 2 },
    { 1, 1, 2, 1, 2, 0, 2, 2, 1, 0, 1, 2, 2, 2, 1, 1 },
    { 0, 1, 2, 0, 1, 1, 2, 2, 2, 0, 0, 1, 2, 1, 1, 0 },
    { 1, 0, 0, 2, 2, 0, 1, 1, 0, 2, 2, 2, 1, 2, 0, 0 },
    { 2, 1, 1, 0, 2, 0, 2, 2, 0, 0, 0, 2, 1, 2, 1, 0 },
    { 1, 2, 0, 0, 2, 2, 1, 1, 2, 0, 2, 1, 0, 0, 1, 1 },
    { 0, 1, 1, 0, 1, 2, 1, 2, 2, 2, 2, 0, 2, 1, 1, 1 },
    { 0, 1, 2, 0, 0, 0, 0, 0, 1, 2, 2, 0, 2, 0, 0, 2 },
    { 0, 0, 1, 0, 1, 1, 1, 0, 2, 1, 0, 1, 1, 2, 0, 1 },
    { 0, 1, 0, 2, 0, 0, 0, 1, 1, 2, 1, 1, 2, 2, 1, 1 },
    { 1, 1, 1, 2, 2, 0, 0, 2, 1, 0, 2, 2, 1, 2, 1, 2 },
    { 0, 2, 1, 1, 2, 1, 0, 0, 0, 0, 2, 0, 0, 1, 1, 0 }
};
*/
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

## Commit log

2026-05-04 Added documentation files
    [ball_castor_raiser.gcode.3mf, ball_castor_raiser.stl, battery_holder_4aa_v2_a.gcode.3mf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]
2026-05-04 Added get_esp32_chip_info and components
    [partitions.csv]
2026-05-04 Added remaining directories
    [partitions.csv]
2026-06-30 Documentation updates
    [master_bom.xlsx]
2026-08-12 Deleted .stl files, sharing TinkerCAD originals now
    [ball_castor_raiser.stl, battery_holder_4aa_v2_a.stl, magnet_holder_disk.stl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]

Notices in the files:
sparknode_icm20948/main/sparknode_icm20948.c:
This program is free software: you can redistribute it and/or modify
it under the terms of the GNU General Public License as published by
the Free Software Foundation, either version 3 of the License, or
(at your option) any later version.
